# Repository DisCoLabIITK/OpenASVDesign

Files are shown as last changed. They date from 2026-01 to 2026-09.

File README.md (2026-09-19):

# OpenASV 160

OpenASV 160 is an open-source, twin-hull autonomous surface vehicle (ASV). This page is a visual index of the design variants in this repository — each section pairs a rendered CAD assembly with a note on what makes that version distinct and links to the folder holding its source files. 

**Use version 2 pipe brackets in Pipe_Brackets_v2 folder.**

**See the Mechanical-Assembly.md file for assembly instructions of baseline option.**

**Ardupilot param files can be found in the Adupilot_Config folder.**

# OpenASV 160 — Design Versions

## Default Model (High Rider)

📁 [`Final_Assembly_160_High_Rider`](Final_Assembly_160_High_Rider/)

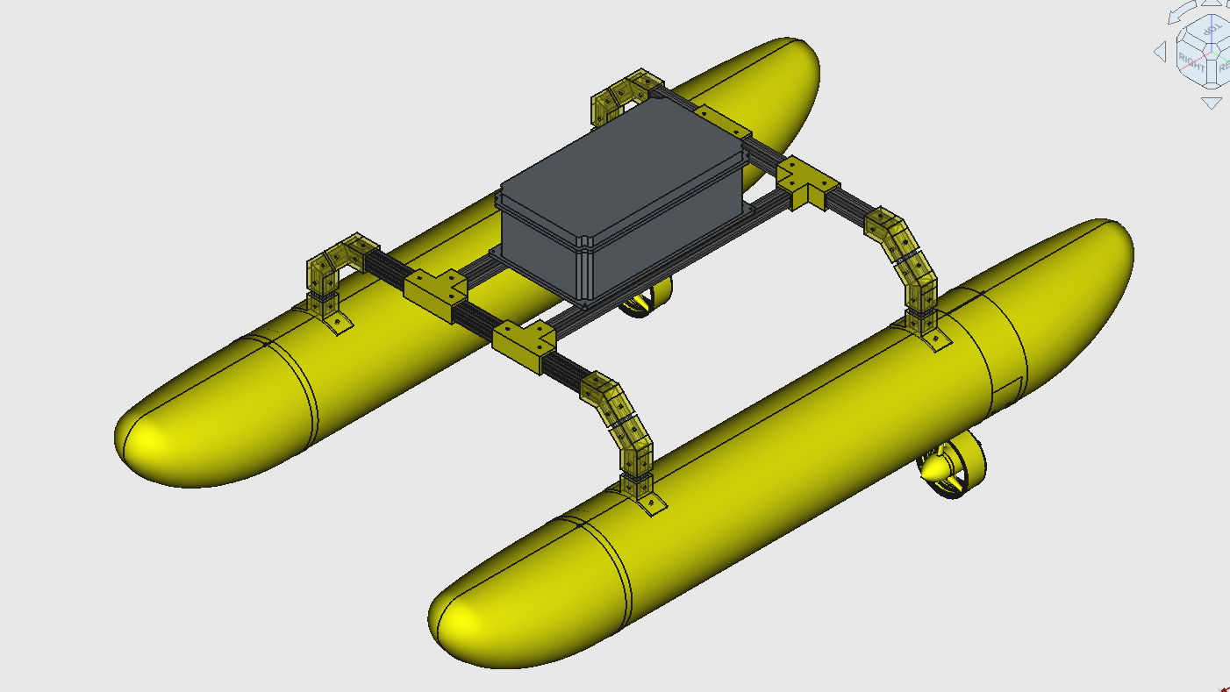
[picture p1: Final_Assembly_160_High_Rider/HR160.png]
Default model


Default model. Higher center of gravity of electronics enclosure to prevent wave water splashing. Fixed differential thrust.

### Exploded View

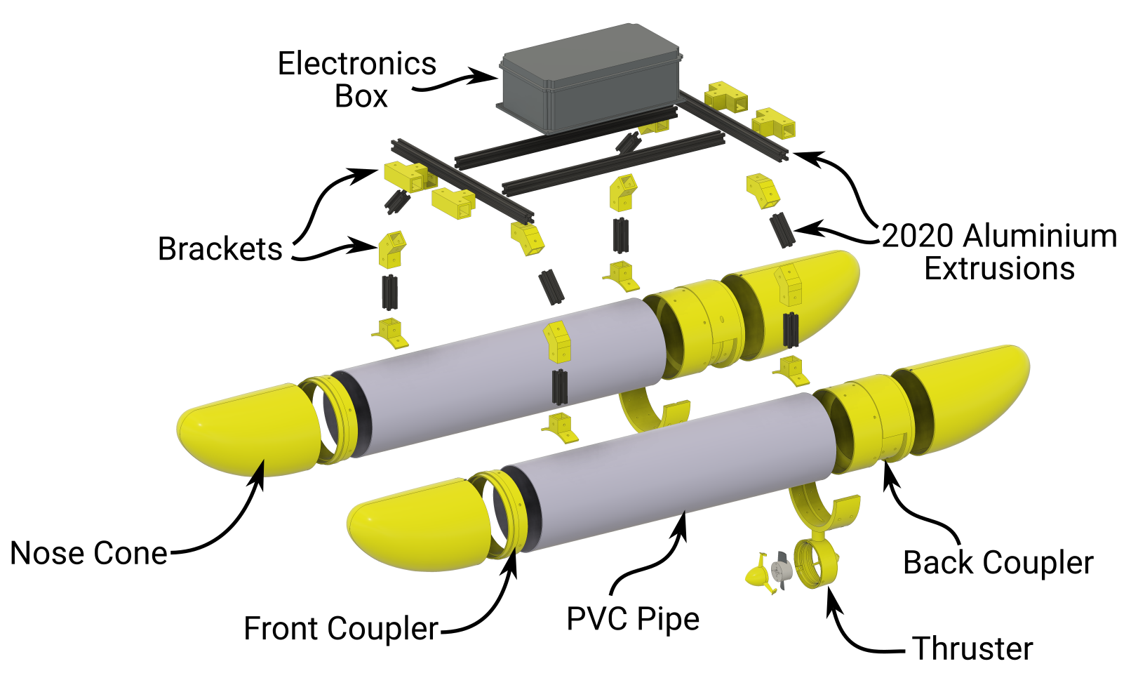
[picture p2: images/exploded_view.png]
Exploded view


Exploded view of the default assembly.

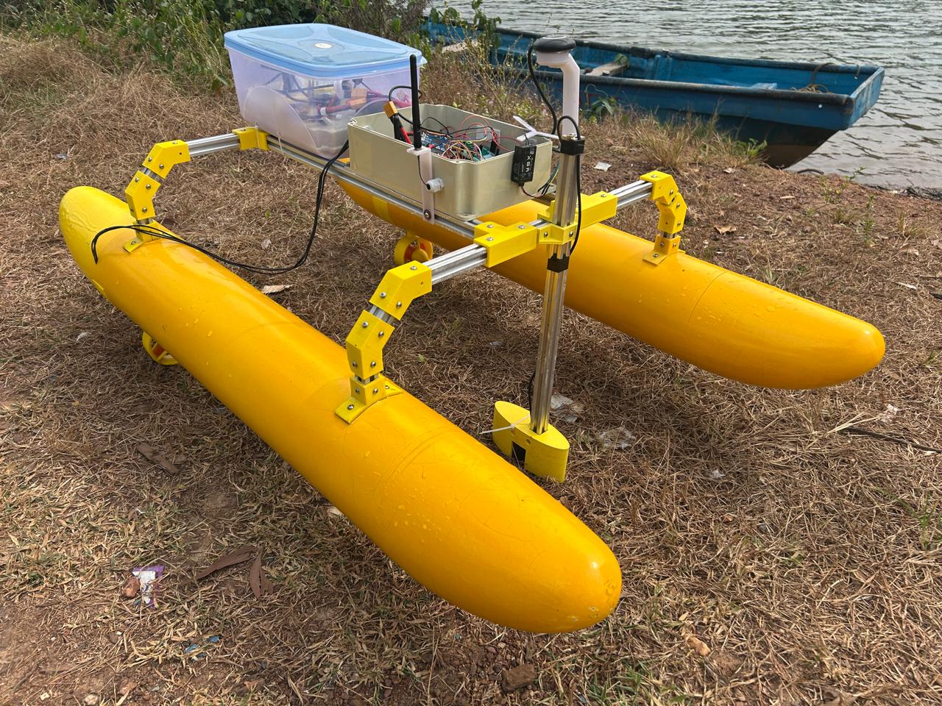
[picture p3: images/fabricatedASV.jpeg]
Fabricated version


Fabricated default version.

## High Rider — Hull Box

📁 [`Final_Assembly_160_High_Rider_HullBox`](Final_Assembly_160_High_Rider_HullBox/)

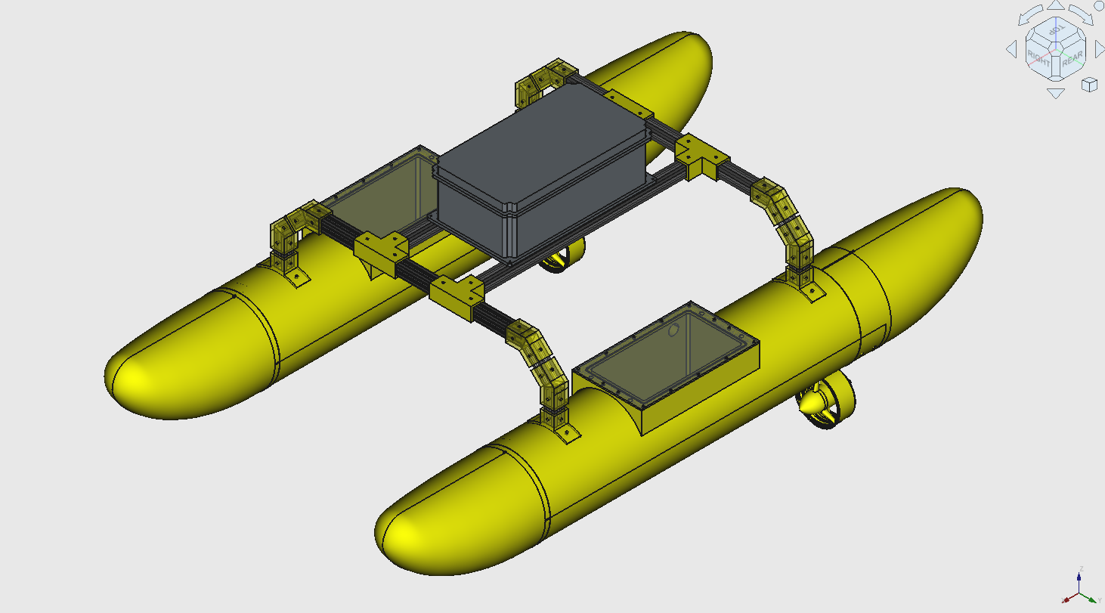
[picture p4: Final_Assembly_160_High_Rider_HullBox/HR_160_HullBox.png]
Hull box version


Version with storage box in the PVC pipe hulls.

## Low Rider

📁 [`Final_Assembly_160_Low_Rider`](Final_Assembly_160_Low_Rider/)

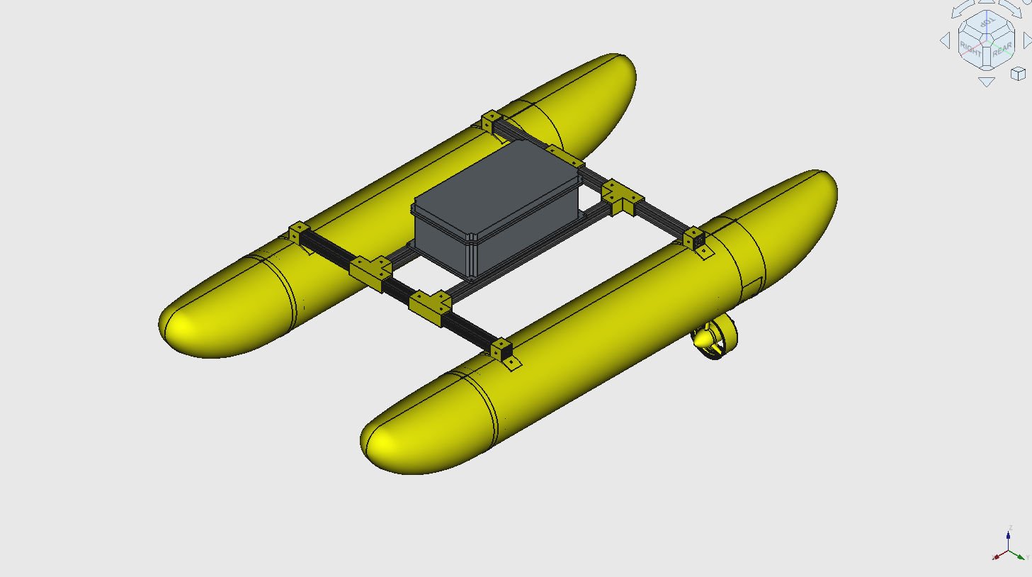
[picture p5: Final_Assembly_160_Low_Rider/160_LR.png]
Low rider version


Version with lower center of gravity of electronics enclosure.

## Aero Drive

📁 [`Final_Assembly_160_High_Rider_Aero`](Final_Assembly_160_High_Rider_Aero/)

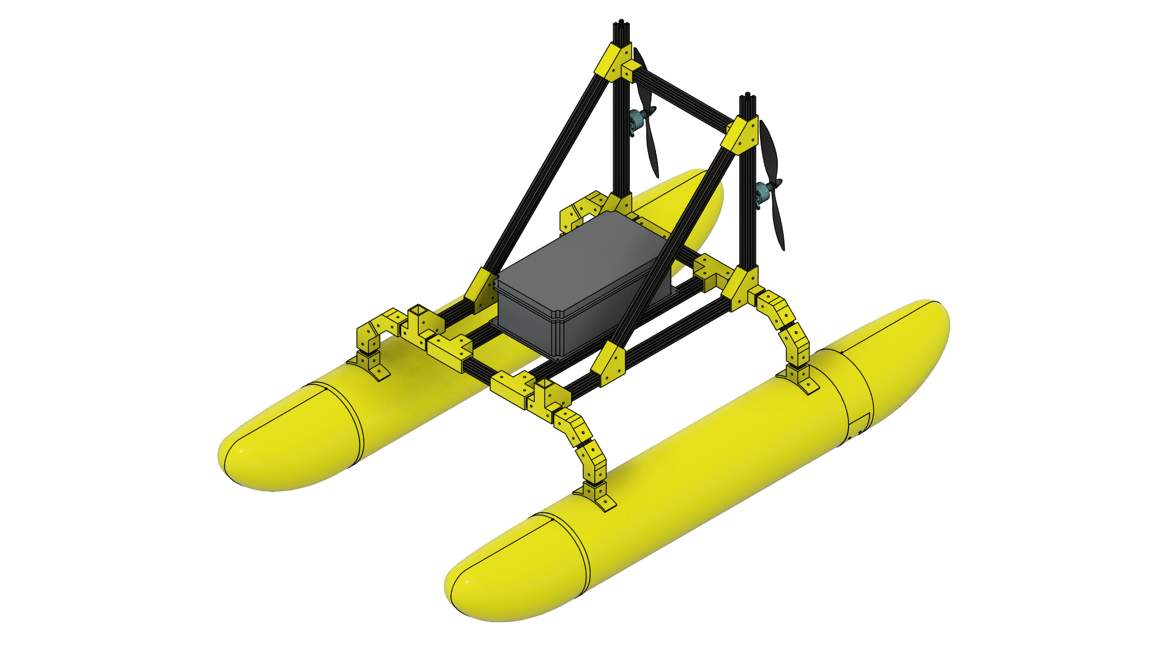
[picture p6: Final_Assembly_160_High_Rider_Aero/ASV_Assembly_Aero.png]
Aero drive version


Version with differential air propeller drive for shallow waters.

## Over-Actuated (Mid-Mount Thrusters)

📁 [`Final_Assembly_160_Low_Rider_3_4DoF`](Final_Assembly_160_Low_Rider_3_4DoF/)

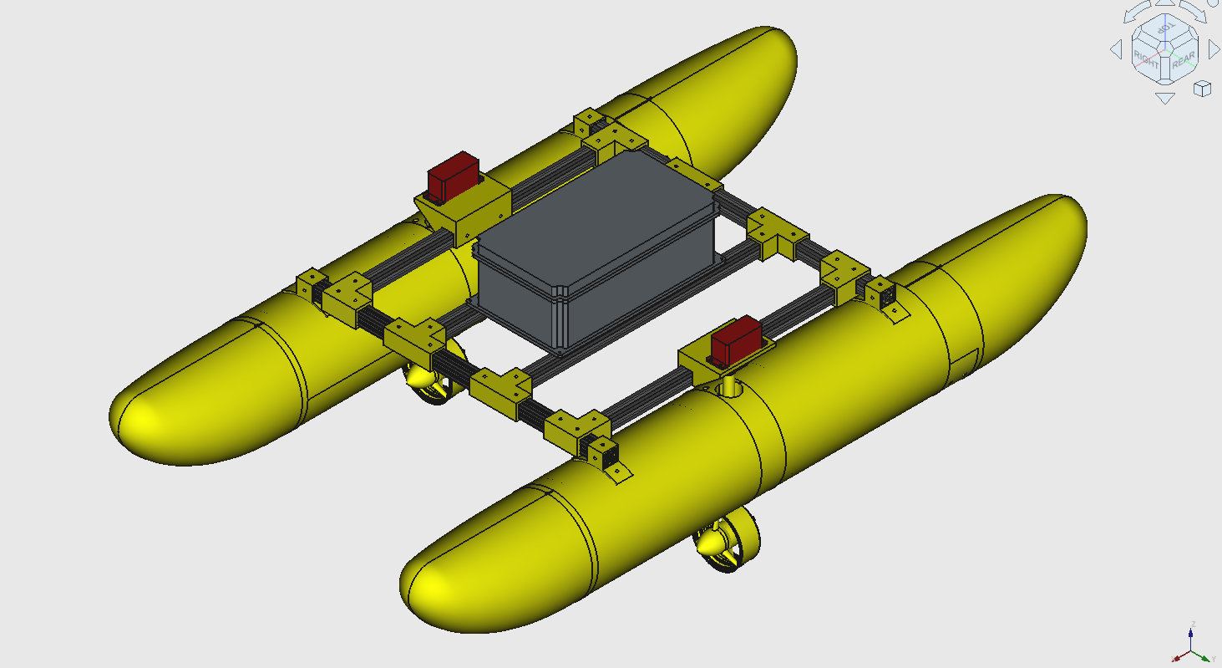
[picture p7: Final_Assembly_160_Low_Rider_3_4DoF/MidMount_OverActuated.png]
Over-actuated version


Overactuated version with mid-hull mounted thrusters, pivotable with servos.

---

**Note:** The [`Pipe_Brackets_v2`](Pipe_Brackets_v2/) folder contains updated hull brackets for aluminium extrusions.

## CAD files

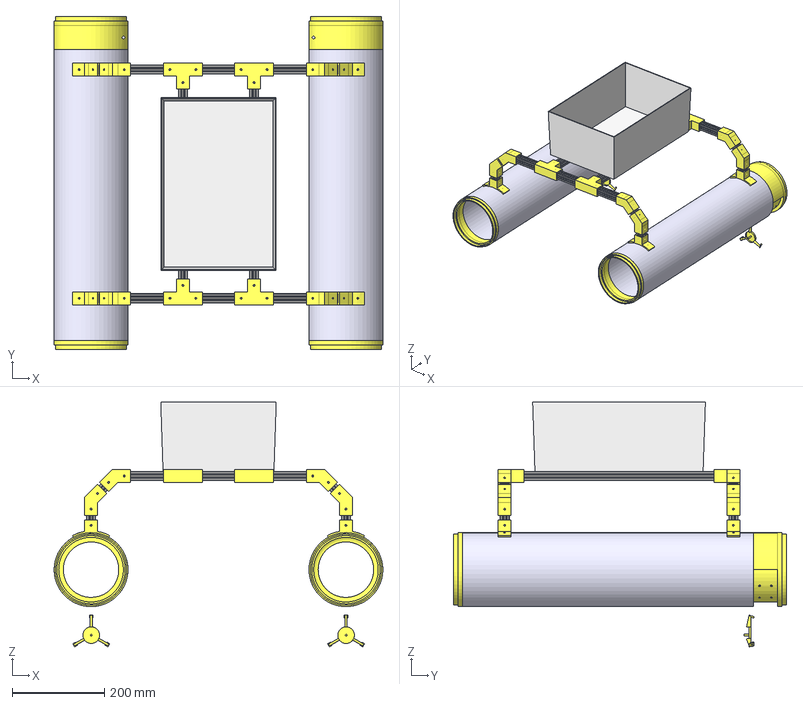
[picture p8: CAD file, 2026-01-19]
Step Files/ASV_Assembly.step
711.7 x 720.8 x 530.2 mm
LCS_Origin
LCS_1 x 4
Coupler002
LCS_Thruster
Pipe_Right x 2
LCS_Back x 2
CouplerFore x 2
2020Bracket_Vertical_Aft_Right x 4
LCS_Hull x 4
2020_Extrusion x 8
Body_2020Bracket_45 x 8
2020_Extrusion008 x 2
Body_2020_T_Bracket003 x 4
2020_Extrusion010 x 2
LCS_001 x 2
Front_Cover x 2
Coupler_Left
LCS_Nose002
LCS_Pipe002
LCS_Bracket002
LCS_Thruster001
LCS_0014
LCS_FrontCoverRight
LCS_0015
LCS_FrontCoverLeft

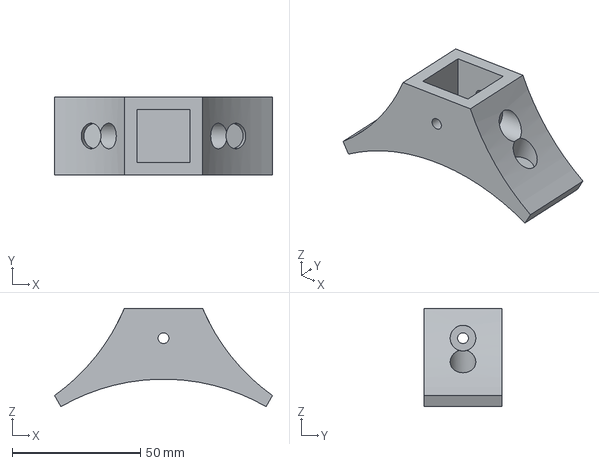
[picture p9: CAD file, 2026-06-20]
Pipe_Brackets_v2/Pipe_Bracket-160_Pipe_Top.step
85.0 x 30.5 x 38.3 mm

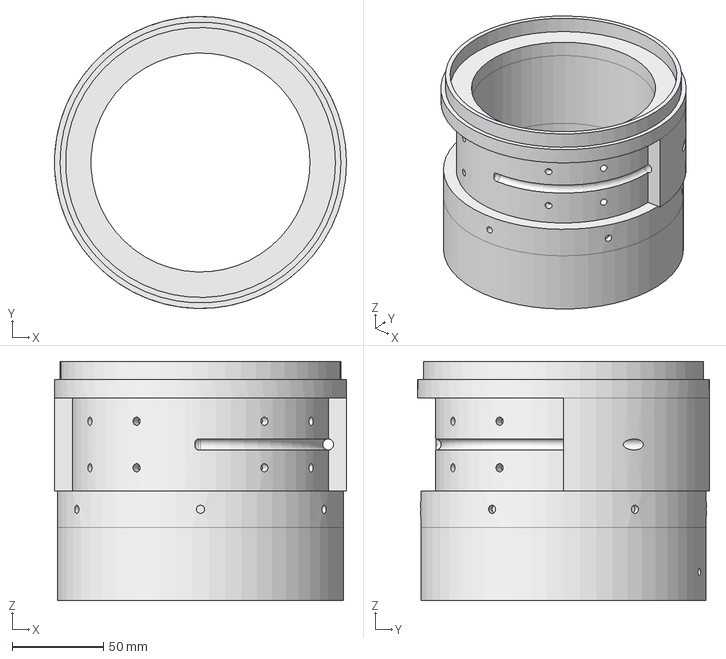
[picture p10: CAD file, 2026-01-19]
Step Files/Coupler_Thrusterv2.step
160.0 x 160.0 x 131.0 mm

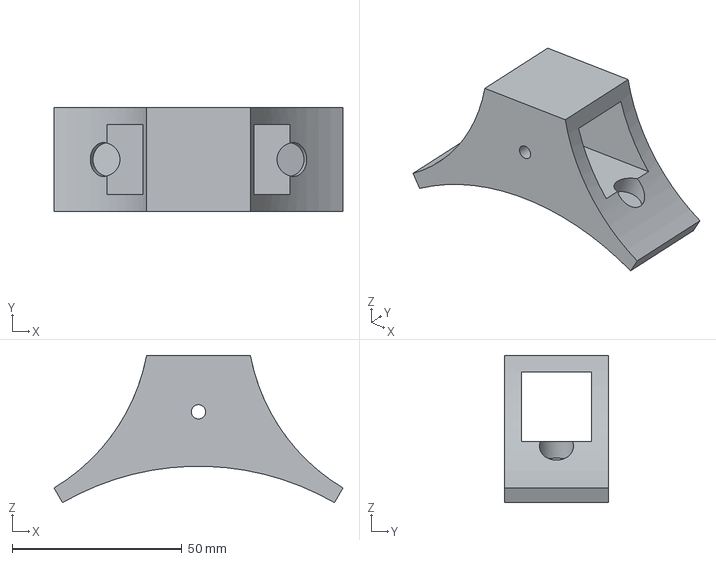
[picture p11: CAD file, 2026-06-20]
Pipe_Brackets_v2/Pipe_Bracket-160_Pipe_Side.step
85.0 x 30.5 x 43.3 mm

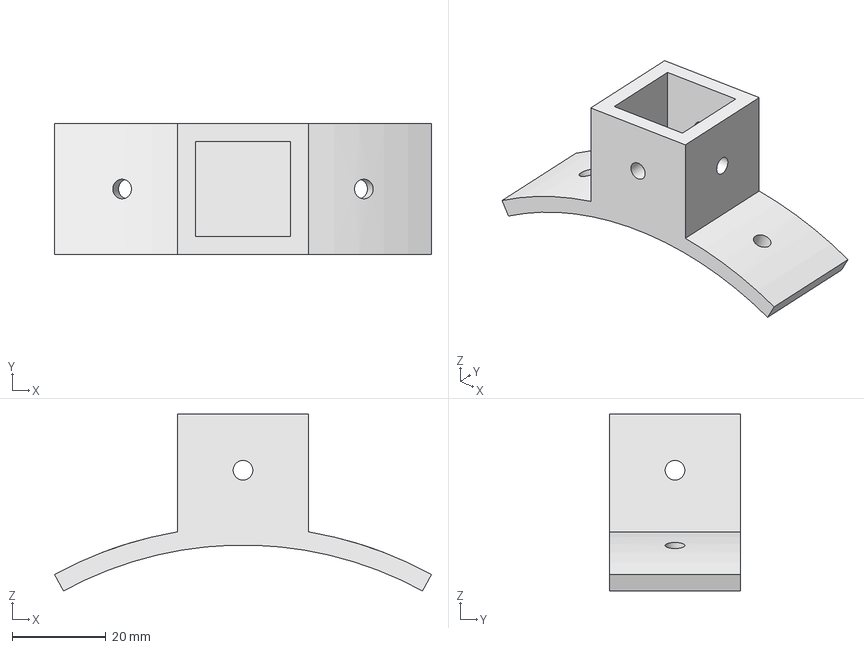
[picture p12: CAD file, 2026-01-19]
Step Files/2020_Bracket_Vertical.step
80.6 x 28.0 x 37.8 mm

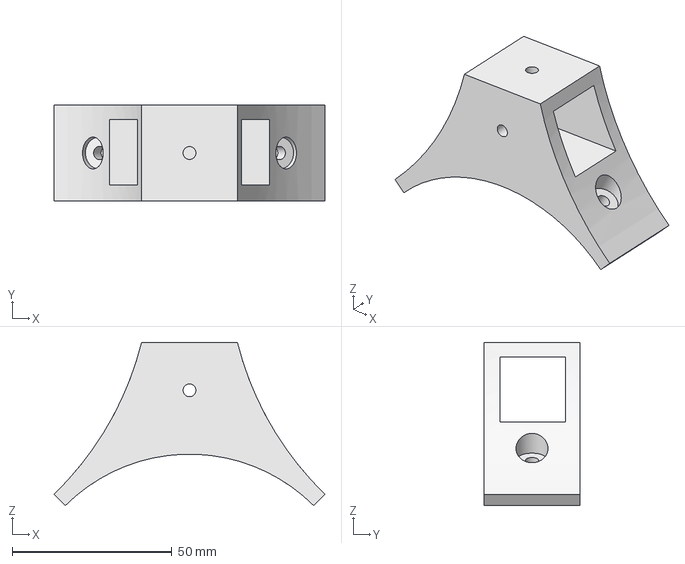
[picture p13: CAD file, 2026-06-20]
Pipe_Brackets_v2/Pipe_Bracket-110_Pipe_Side.step
84.9 x 30.0 x 51.1 mm

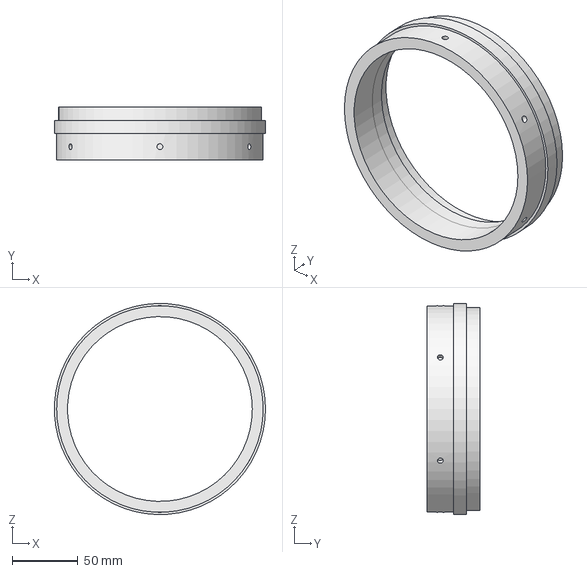
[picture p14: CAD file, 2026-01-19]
Step Files/Coupler_Fore.step
159.9 x 40.0 x 159.9 mm

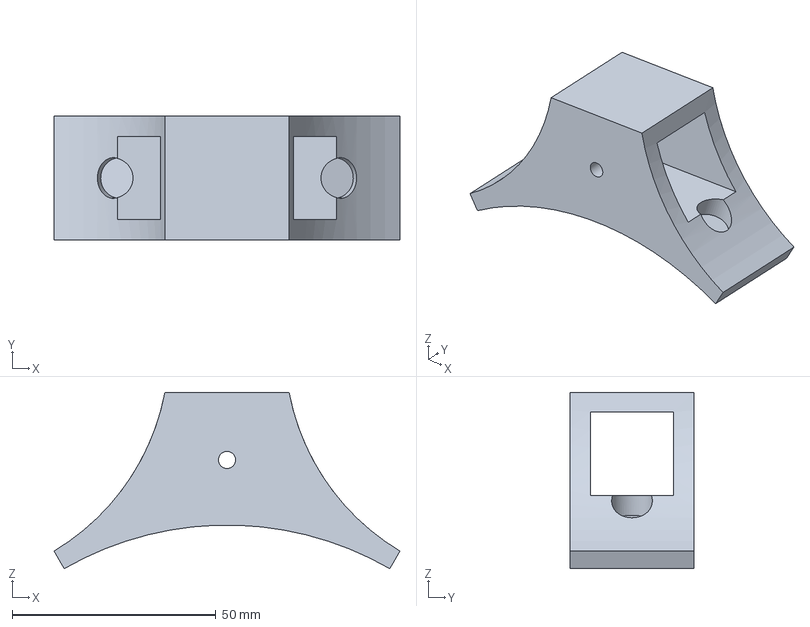
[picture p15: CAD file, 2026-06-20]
Pipe_Brackets_v2/Pipe_Bracket.FCStd
85.0 x 30.5 x 43.3 mm

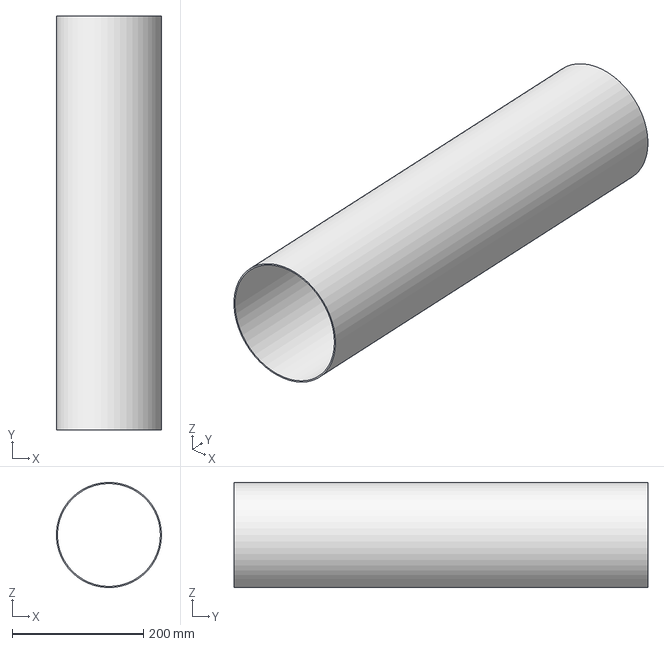
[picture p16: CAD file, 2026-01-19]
Step Files/Pipe.step
159.8 x 629.8 x 159.9 mm

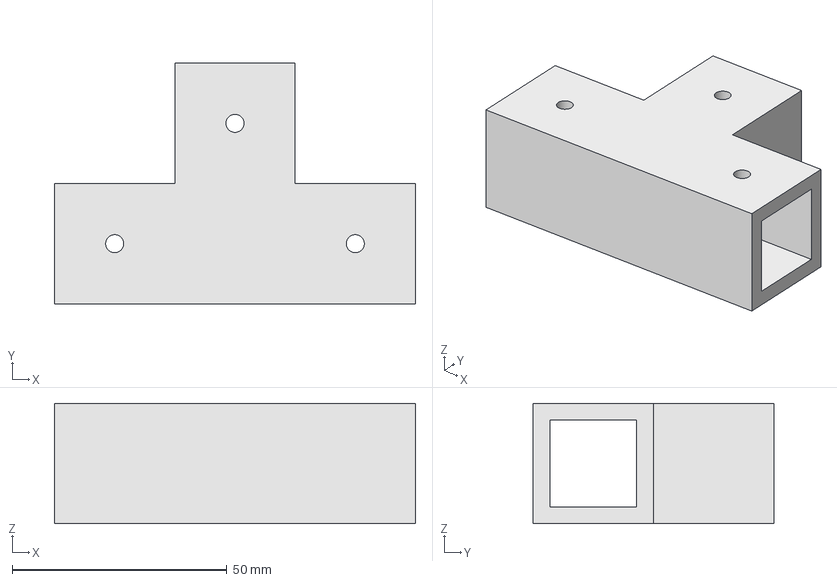
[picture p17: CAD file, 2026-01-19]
Step Files/2020_Bracket_T.step
84.0 x 56.0 x 28.0 mm

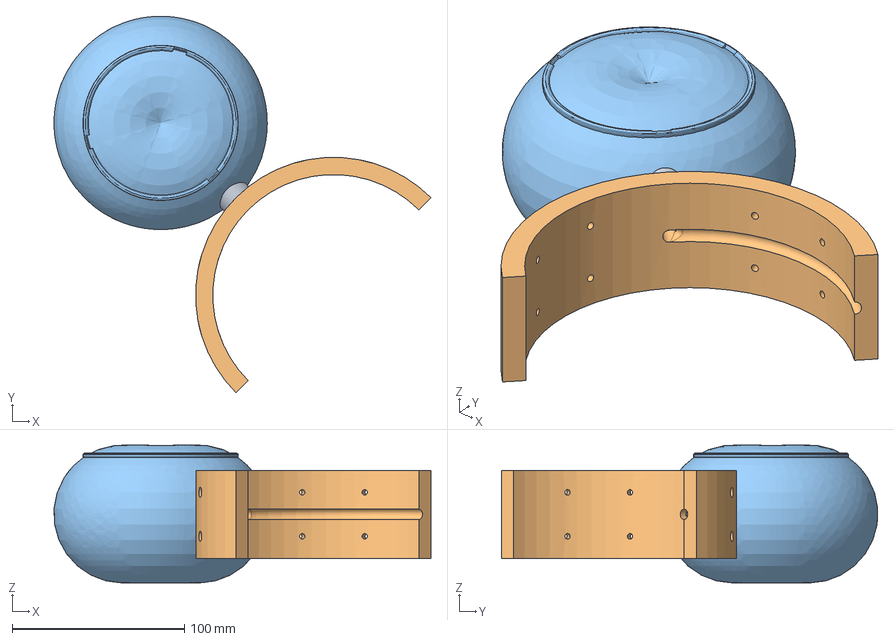
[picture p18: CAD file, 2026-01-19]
Step Files/Thruster_Mount_Right.step
218.7 x 218.4 x 80.0 mm
Thruster_Neck001
Thruster_Bracket001
Nozzle 038

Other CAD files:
Final_Assembly_160_High_Rider/Assembly_Final_160_HR.FCStd
Final_Assembly_160_High_Rider_Aero/Assembly_Final_160_HR_Aero.FCStd
Final_Assembly_160_High_Rider_HullBox/Assembly_Final_160_HR.FCStd
Final_Assembly_160_Low_Rider/Assembly_Final_LR.FCStd
Final_Assembly_160_Low_Rider_3_4DoF/Assembly_Final_LR.FCStd
Step Files/Coupler_Thruster.step
Step Files/Thruster_Mount_Left.step
Step Files/2020_Bracket_45.step
Step Files/Coupler_Thruster_Right.step

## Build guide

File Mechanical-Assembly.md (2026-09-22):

# Mechanical Assembly

This page describes the step-by-step mechanical assembly of the OpenASV twin-hull platform, from 3D-printed part preparation through thruster mounting.

## Bill of Materials

| # | Part | Specification | Qty |
|---|---|---|-----|
| 1 | PVC pipe | 160 mm dia × 630 mm length, 1.75 mm wall | 2 |
| 2 | Socket head screws | M3 × 12 mm, stainless steel | 16 |
| 3 | Socket head screws | M4 × 16 mm, stainless steel | 8 |
| 4 | Socket head screws | M4 × 10 mm, stainless steel | 104 |
| 5 | Nuts | M3, stainless steel | 16 |
| 6 | Nuts | M4, stainless steel | 8 |
| 7 | Hammer T-nuts | M4, stainless steel | 104 |
| 8 | 2020 aluminium extrusion | 100 mm length | 8 |
| 9 | 2020 aluminium extrusion | 440 mm length | 2 |
| 10 | 2020 aluminium extrusion | 465 mm length | 2 |
| 11 | Epoxy resin (casting) | — | 500 ml |
| 12 | Bond epoxy adhesive (2-part) | — | 90 g |
| 13 | Heat Inserts | M3 × 6mm | 16 |
| 14 | Heat Inserts **(Optional)** | M3 × 4mm | 32 |

**3D-printed parts:** print the required quantities of each part from the CAD renders (front nose cones, rear nose cones, front couplers, rear couplers, vertical brackets, cable guides).

## Tools & Consumables

- Drill with 4 mm bit
- Soldering iron (for heat inserts)
- 100 grit and 200 grit sandpaper
- Masking tape and adhesive tape
- Spray paint (colour of your choice)

---

## Assembly Steps

### Step 0 — Prepare the 3D-printed parts

Clean all 3D-printed parts and lightly sand them with 100 grit sandpaper.

### Step 1 — Install heat inserts in the rear couplers

Set 8 heat inserts into the holes within the dashed blue rectangle shown below, on **both** rear couplers. These accept the thruster mounting screws (M3).

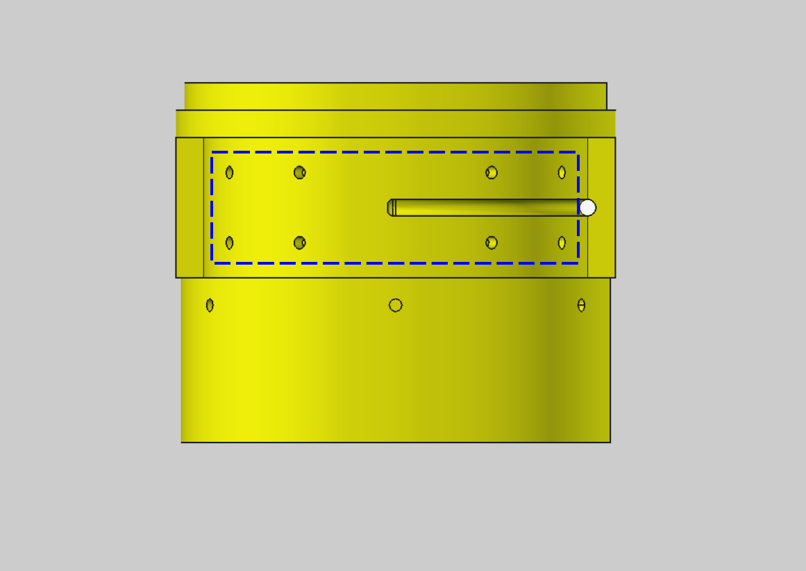
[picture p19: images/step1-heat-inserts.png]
Heat insert locations on the rear coupler


### Step 2 — Bond the front couplers to the front nose cones

Prepare the 2-part Bond epoxy adhesive in small batches. Apply the adhesive all around the **shorter lip** of the front coupler as shown. Align the groove on the coupler with the tab on the nose cone and join them together. Repeat for the second set.

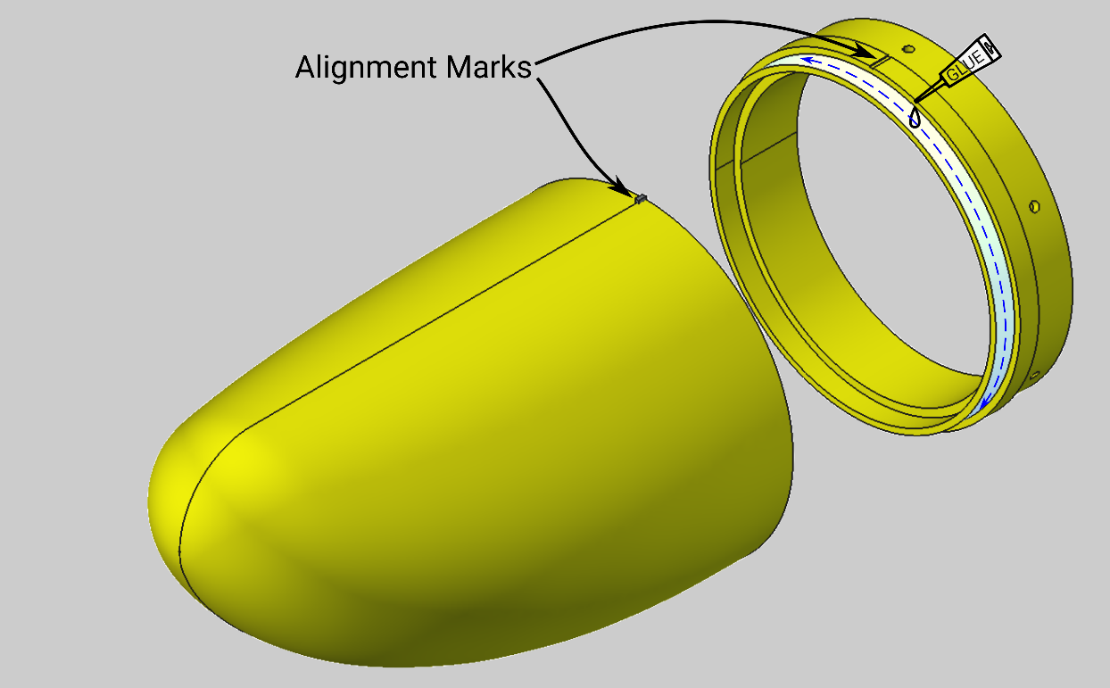
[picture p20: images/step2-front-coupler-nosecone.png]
Epoxy application on the front coupler shorter lip


### Step 3 — Bond the rear couplers to the rear nose cones

Repeat the same process to join each rear nose cone to its rear coupler.

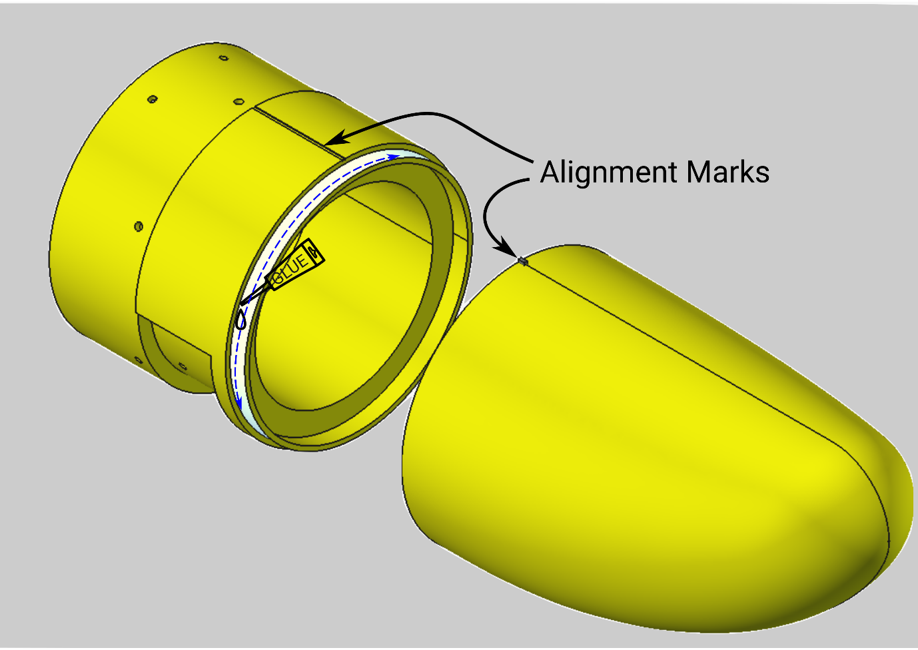
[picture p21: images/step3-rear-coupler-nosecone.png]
Joining the rear nose cone and rear coupler


### Step 4 — Fit the front vertical bracket to the PVC pipe

On the **front** end of the pipe, position the vertical bracket **73 mm** from the edge. PVC pipes generally have a vertical printed line along the body — use this line to align with bracket screw hole 1 as shown.

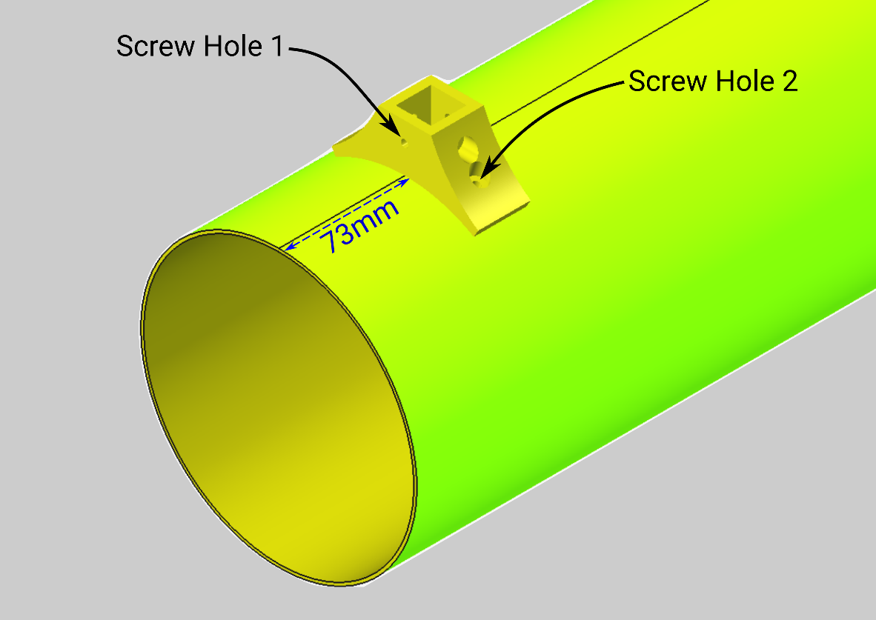
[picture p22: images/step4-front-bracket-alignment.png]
Front bracket alignment, 73 mm from the pipe edge


Holding the bracket in the aligned position, drill 4 mm holes through screw hole 2 and its counterpart on the other side of the bracket. Fasten the bracket to the pipe with 2 × M4×16 screws and M4 nuts. Optionally apply epoxy adhesive between the pipe and the bracket underside for a more robust, waterproof fixture.

### Step 5 — Fit the rear vertical bracket

Repeat the process on the other end of the pipe, but position the bracket **29 mm** from the edge. Repeat Steps 4–5 on the second hull.

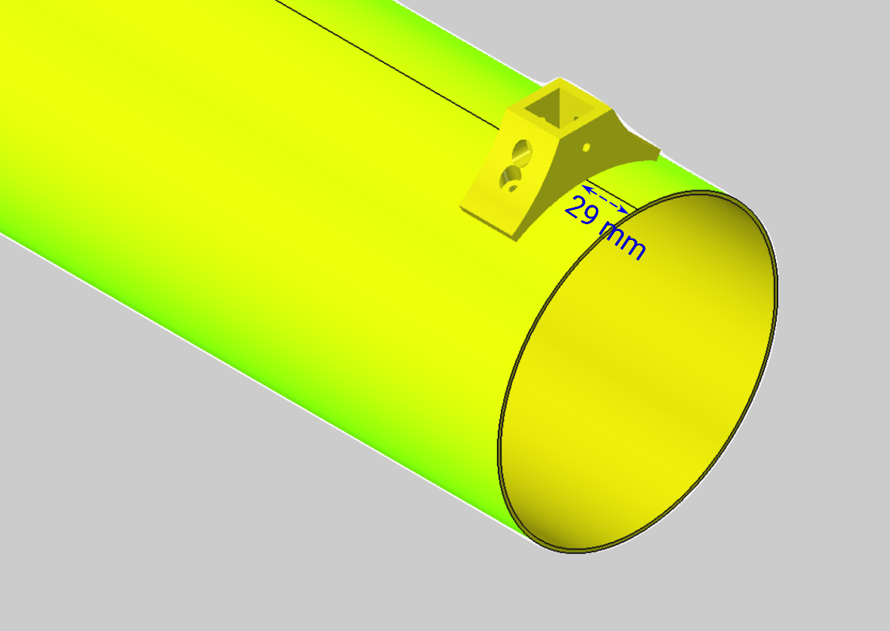
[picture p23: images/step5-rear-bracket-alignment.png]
Rear bracket alignment, 29 mm from the pipe edge


### Step 6 — Bond the front nose-coupler assembly to the pipe

Coat epoxy adhesive on the **longer lip** of the front coupler as shown. Use the groove on the coupler and the printed line on the pipe to align.

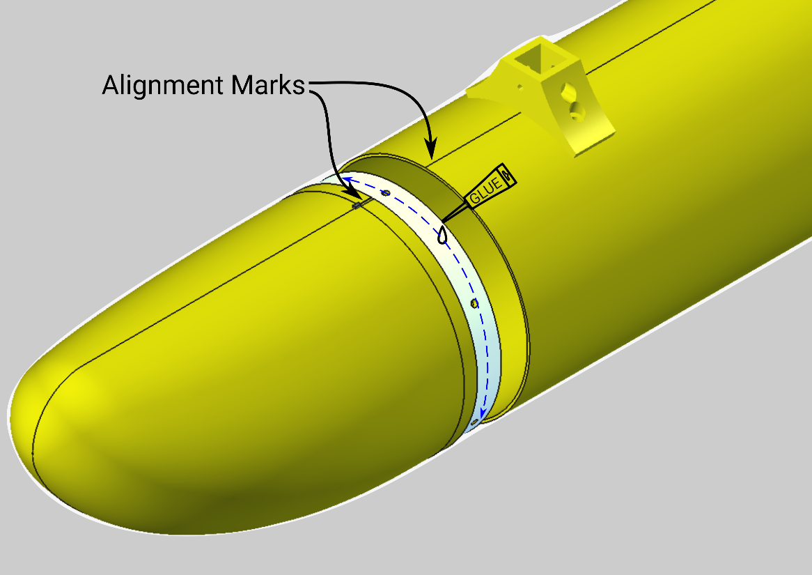
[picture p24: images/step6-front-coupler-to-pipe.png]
Bonding the front coupler assembly to the PVC pipe


### Step 7 — Bond the rear nose-coupler assembly to the pipe

Repeat for the rear coupler, then repeat both steps on the second hull.

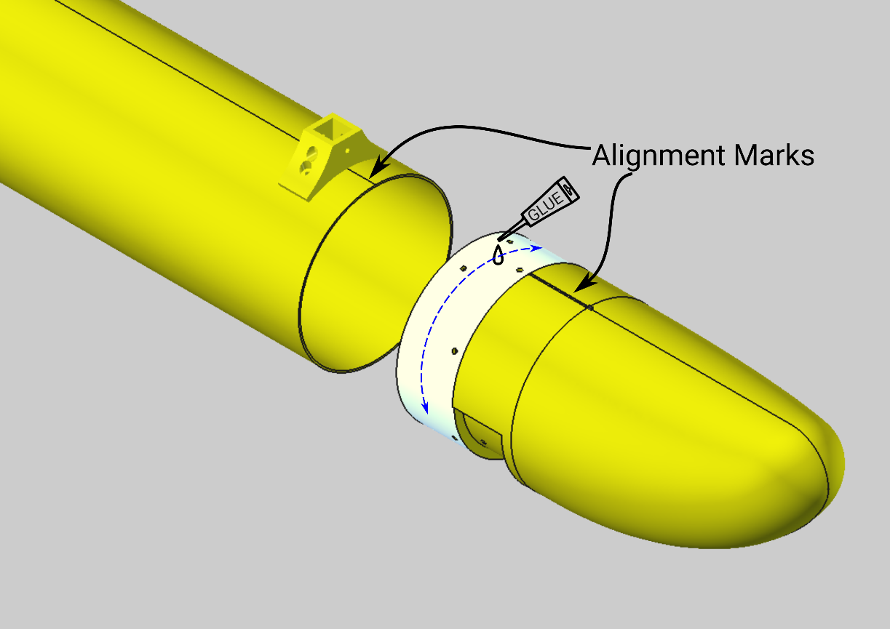
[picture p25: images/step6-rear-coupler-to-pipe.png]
Bonding the rear coupler assembly to the PVC pipe


After this step you should have two complete hulls:

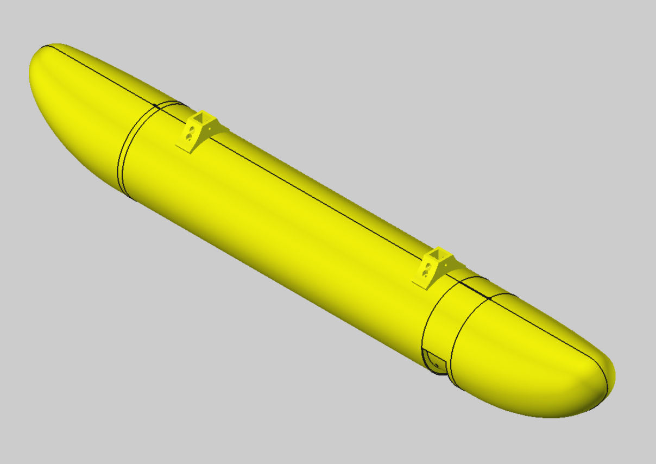
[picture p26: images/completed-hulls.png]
Two completed hulls


### Step 8 — Seal, sand and paint the hulls

Coat the 3D-printed parts with a thin layer of **epoxy resin** (casting resin, not adhesive). Once dry, lightly sand the entire hulls with 200 grit sandpaper and spray paint in the colour of your choice.

> **Important:** mask the heat insert holes during both the epoxy coating and spray painting operations.

### Step 9 — Assemble the top half of the extrusion brace

Assemble the top half of the aluminium extrusion brace that connects the two hulls, as shown below. The box spacing depends on your electronics enclosure size and can be adjusted to suit your needs. Fasten the T-brackets to the extrusions using M4×10 screws and M4 hammer T-nuts.

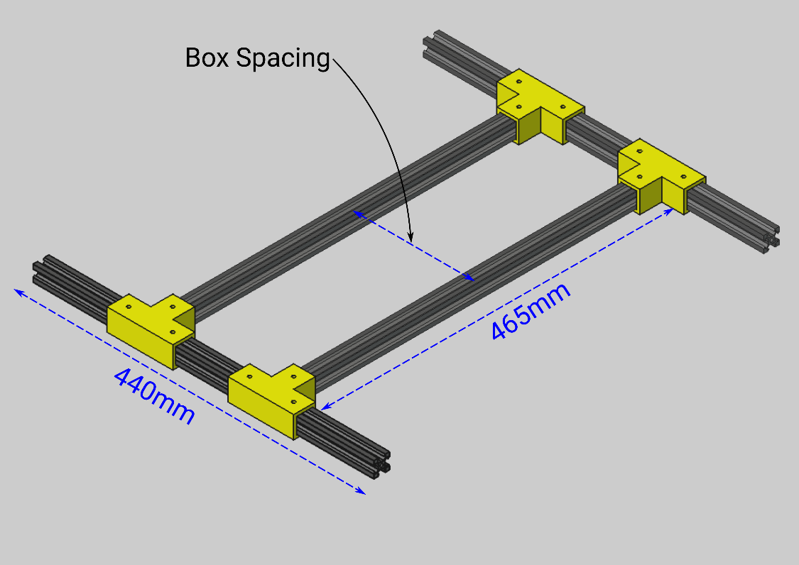
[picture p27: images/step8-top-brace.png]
Top half of the aluminium extrusion brace


### Step 10 — Assemble the 45° arms

Assemble the 45° arms using the 100 mm extrusions and 45° brackets.

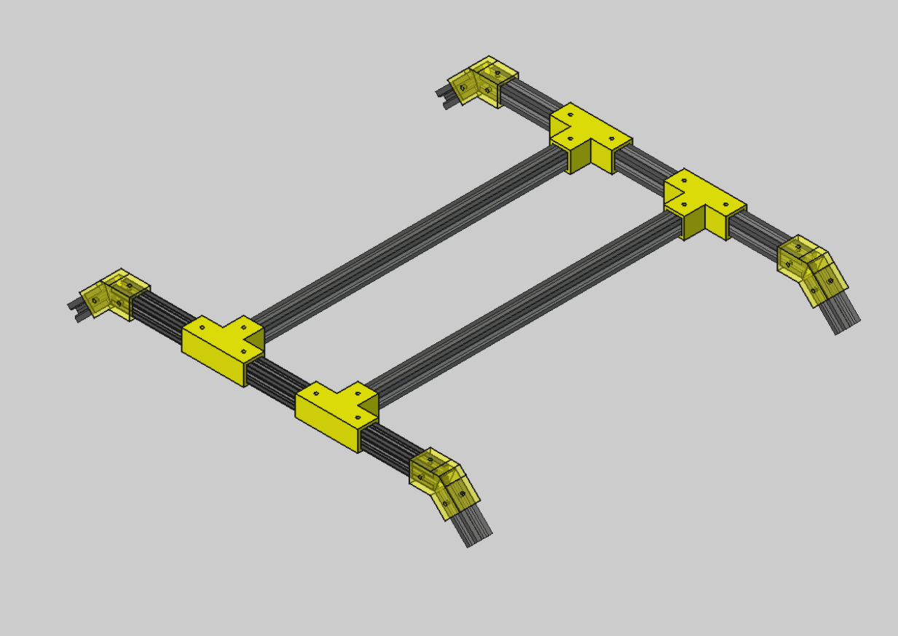
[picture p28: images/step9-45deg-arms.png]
45-degree arm assembly


### Step 11 — Assemble the vertical section

Assemble the vertical section; the completed brace should look as shown below. Place the brace on a flat surface and adjust the vertical and 45° arm lengths so that the frame sits level.

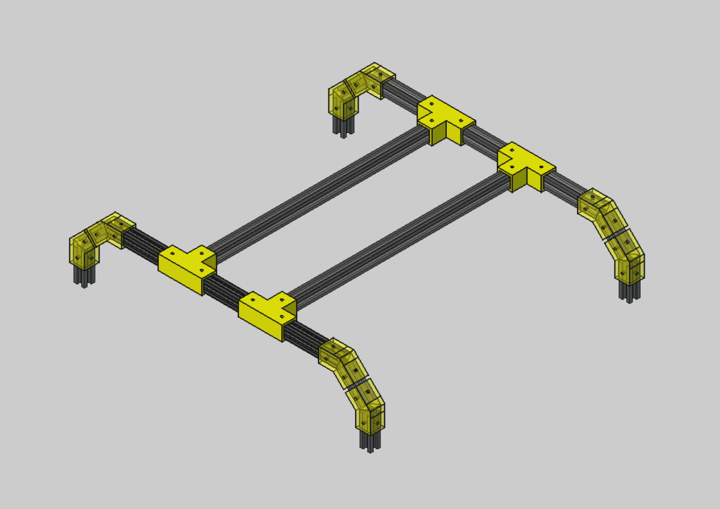
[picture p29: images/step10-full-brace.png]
Completed brace frame


### Step 12 — Join the brace to the hulls

Join the completed brace to the two hulls as shown.

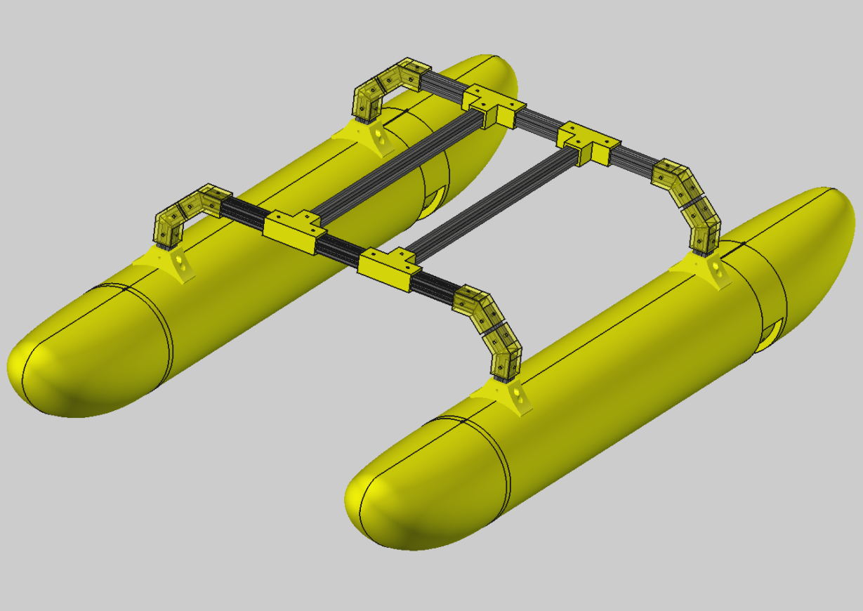
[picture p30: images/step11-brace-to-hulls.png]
Brace joined to the two hulls


### Step 13 — Assemble and mount the thrusters

Assemble the thrusters as per the instructions in the OpenThruster paper. Route the motor cables through the cable guide as shown; use adhesive tape to hold the cables in place if required. Affix each assembled thruster to the rear coupler using M3×12 screws.

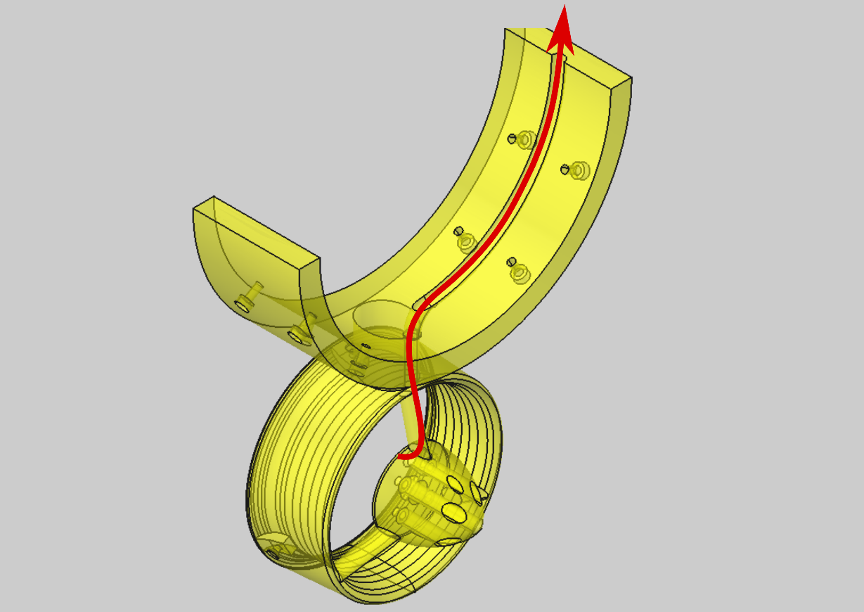
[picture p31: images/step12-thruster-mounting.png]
Thruster mounting and cable routing


---

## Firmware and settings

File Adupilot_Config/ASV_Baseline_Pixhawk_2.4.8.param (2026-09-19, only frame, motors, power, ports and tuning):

ATC_SPEED_D,0
ATC_SPEED_D_FF,0
ATC_SPEED_FF,0
ATC_SPEED_FLTD,0
ATC_SPEED_FLTE,10
ATC_SPEED_FLTT,0
ATC_SPEED_I,0.2
ATC_SPEED_IMAX,1
ATC_SPEED_NEF,0
ATC_SPEED_NTF,0
ATC_SPEED_P,0.2
ATC_SPEED_PDMX,0
ATC_SPEED_SMAX,0
ATC_STR_ACC_MAX,120
ATC_STR_ANG_P,2
ATC_STR_RAT_D,0
ATC_STR_RAT_D_FF,0
ATC_STR_RAT_FF,0.2
ATC_STR_RAT_FLTD,0
ATC_STR_RAT_FLTE,10
ATC_STR_RAT_FLTT,0
ATC_STR_RAT_I,0.2
ATC_STR_RAT_IMAX,1
ATC_STR_RAT_MAX,120
ATC_STR_RAT_NEF,0
ATC_STR_RAT_NTF,0
ATC_STR_RAT_P,0.2
ATC_STR_RAT_PDMX,0
ATC_STR_RAT_SMAX,0
BATT_MONITOR,0
BATT2_MONITOR,0
BATT3_MONITOR,0
BATT4_MONITOR,0
BATT5_MONITOR,0
BATT6_MONITOR,0
BATT7_MONITOR,0
BATT8_MONITOR,0
BATT9_MONITOR,0
FLTMODE_GCSBLOCK,0
FRAME_CLASS,2
FRAME_TYPE,0
INS_GYRO_FILTER,4
INS_HNTCH_ENABLE,0
MOT_PWM_FREQ,16
MOT_PWM_TYPE,0
MOT_SAFE_DISARM,0
MOT_SLEWRATE,100
MOT_SPD_SCA_BASE,1
MOT_STR_THR_MIX,0.5
MOT_THR_MAX,100
MOT_THR_MIN,0
MOT_THST_ASYM,1
MOT_THST_EXPO,0
MOT_VEC_ANGLEMAX,0
SERIAL0_BAUD,115
SERIAL0_PROTOCOL,2
SERIAL1_BAUD,921
SERIAL1_OPTIONS,0
SERIAL1_PROTOCOL,2
SERIAL2_BAUD,57
SERIAL2_OPTIONS,0
SERIAL2_PROTOCOL,2
SERIAL3_BAUD,230
SERIAL3_OPTIONS,0
SERIAL3_PROTOCOL,5
SERIAL4_BAUD,230
SERIAL4_OPTIONS,0
SERIAL4_PROTOCOL,5
SERIAL5_BAUD,57
SERIAL5_OPTIONS,0
SERIAL5_PROTOCOL,-1
SERVO1_FUNCTION,73
SERVO1_MAX,1900
SERVO1_MIN,1100
SERVO1_REVERSED,0
SERVO1_TRIM,1480
SERVO2_FUNCTION,0
SERVO2_MAX,1900
SERVO2_MIN,1100
SERVO2_REVERSED,0
SERVO2_TRIM,1500
SERVO3_FUNCTION,74
SERVO3_MAX,1900
SERVO3_MIN,1100
SERVO3_REVERSED,0
SERVO3_TRIM,1480
SERVO4_FUNCTION,0
SERVO4_MAX,1900
SERVO4_MIN,1100
SERVO4_REVERSED,0
SERVO4_TRIM,1500
SERVO5_FUNCTION,0
SERVO5_MAX,1900
SERVO5_MIN,1100
SERVO5_REVERSED,0
SERVO5_TRIM,1500
SERVO6_FUNCTION,0
SERVO6_MAX,1900
SERVO6_MIN,1100
SERVO6_REVERSED,0
SERVO6_TRIM,1500
SERVO7_FUNCTION,0
SERVO7_MAX,1900
SERVO7_MIN,1100
SERVO7_REVERSED,0
SERVO7_TRIM,1500
SERVO8_FUNCTION,0
SERVO8_MAX,1900
SERVO8_MIN,1100
SERVO8_REVERSED,0
SERVO8_TRIM,1500
SERVO9_FUNCTION,0
SERVO9_MAX,1900
SERVO9_MIN,1100
SERVO9_REVERSED,0
SERVO9_TRIM,1500

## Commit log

2026-01-19 Upload designs
    [2020_Bracket_45.step, 2020_Bracket_T.step, 2020_Bracket_Vertical.step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]
2026-06-20 Updated Files.
    [ASV160_Parts-Aero_Brace.step, ASV160_Parts-Aero_Brace_T.step, ASV160_Parts-Aero_ThrusterBlank.step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]
2026-09-12 Pixhawk Param File Upload
    Pixhawk 2.4.8 Configuration Parameter file.
    [ASV_Ardupilot_Rover_Params_12-12-2025.param]
2026-09-19 Modified main readme to indicated assembly instructions
2026-09-19 Ardupilot Parameters added.
    [ASV_Baseline_Pixhawk_2.4.8.param, ASV_Sonar_Pixhawk_2.4.8.param]
2026-09-22 Added heat insert dimentions.
